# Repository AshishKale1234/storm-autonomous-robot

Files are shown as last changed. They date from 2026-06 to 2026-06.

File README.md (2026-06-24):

# Autonomous Ball-Launching Robot — STORM Competition

**ME 588 Mechatronics | Purdue University | Spring 2026**

An autonomous ground robot that follows IR-guided tape paths, classifies opponent-controlled targets via IR beacon frequency detection, and launches foam balls using a BLDC flywheel — all within a 2:30 match window from a single button press.

---

## Overview

The STORM (Send Teams Orbs to Remain Monarchs) competition places two robots on a 4 ft x 8 ft field. Each robot starts at HOME BASE, follows taped paths to four HILLs (raised buckets 12 inches above the surface), reads IR beacons to determine opponent allegiance (750 Hz = Blue, 1500 Hz = Red), and launches foam balls to flip control. Most HILLs at time expiry wins.

Team 12 (**TREBUCHET**) achieved full autonomous operation across multiple complete 2:30 runs: correct navigation to all four junctions, accurate IR classification, and consistent ball delivery into opponent buckets.

| Side | Top | Front |
|:---:|:---:|:---:|
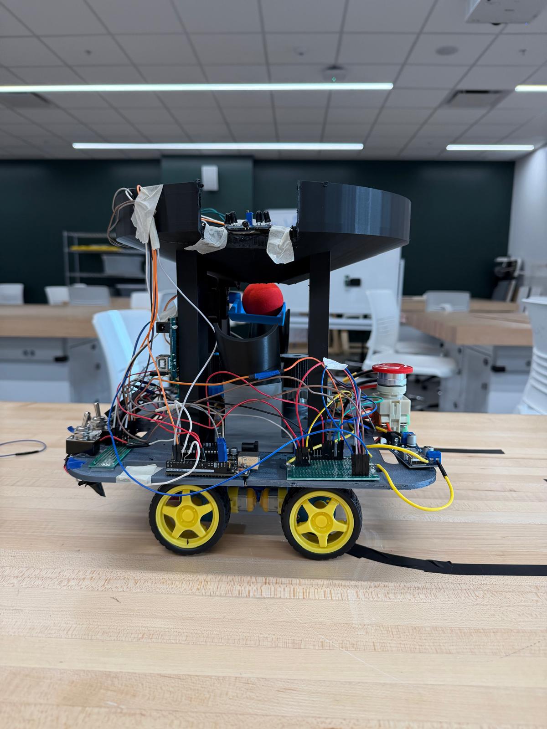
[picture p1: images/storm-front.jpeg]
Side view
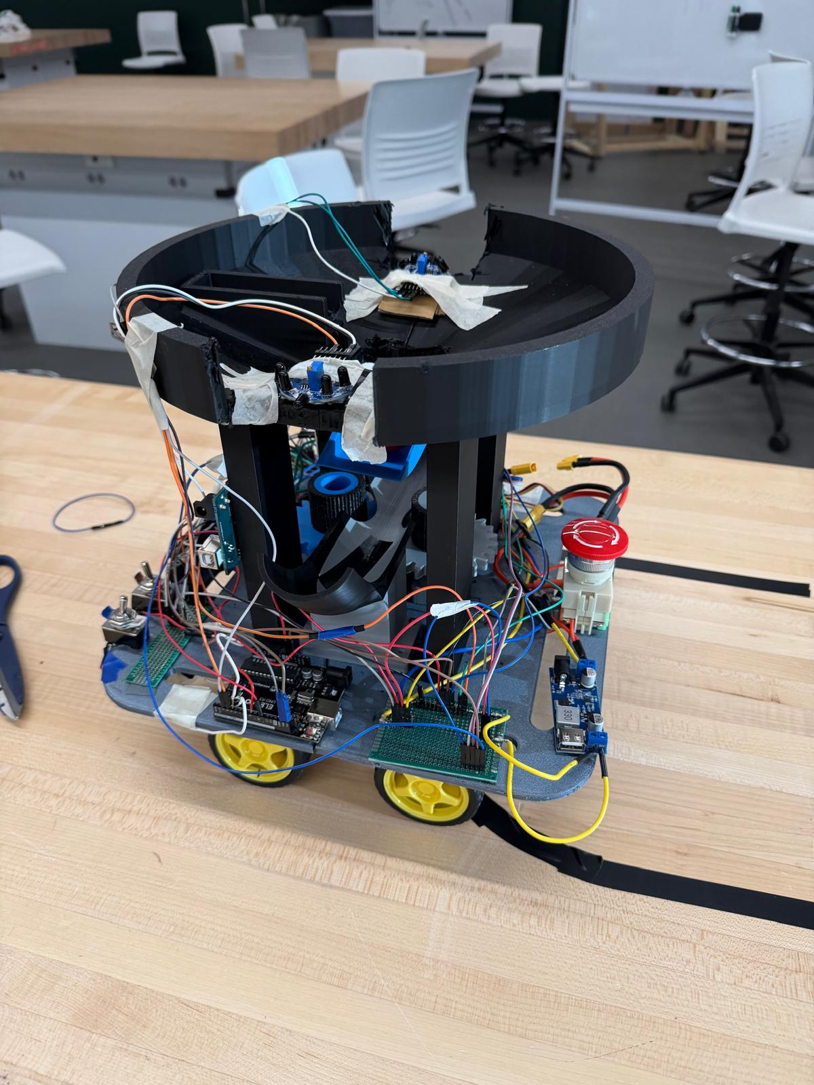
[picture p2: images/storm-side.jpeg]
Top view
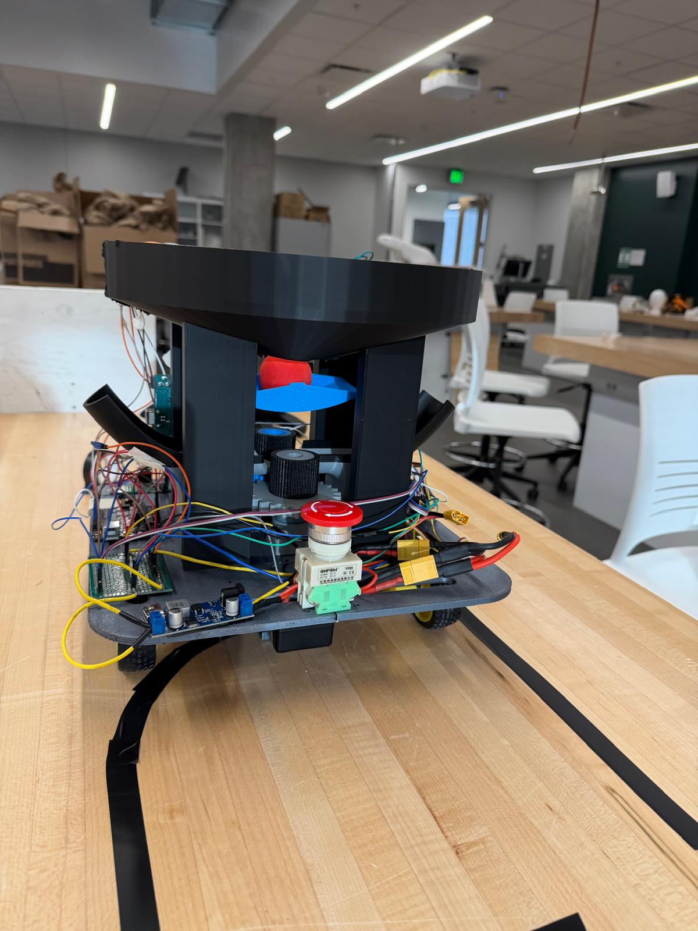
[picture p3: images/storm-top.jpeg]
Front view
|  |  |  |

---

## System Architecture

```
                 +-----------------+
                 |   Arduino 1     |  IR sensing, game timer, LCD, serial TX
  IR Sensor 1 --| D2 (interrupt)  |
  IR Sensor 2 --| D3 (interrupt)  |
  Start Toggle--| D4              |
  Team Toggle --| D5              |
      LCD I2C --| A4/A5           |
                 |   D11 (TX) ----+------> D10 (RX)  |
                 +-----------------+                   |
                                                       v
                 +-----------------+
                 |   Arduino 2     |  Motion, FSM, launcher
  SparkFun Arr--| A4/A5 (I2C)    |
  PCA9685 0x40--| A4/A5 (I2C)    |--> L298N --> 4x DC Motors
  PCA9685 0x41--| A4/A5 (I2C)    |--> ESC  --> BLDC + Flap Servo
                 +-----------------+
```

I2C addresses: `0x3E` line array, `0x40` drive PCA9685 (1000 Hz), `0x41` shooter PCA9685 (50 Hz), `0x27` LCD (Arduino 1).

---

## Hardware

| Component | Part |
|---|---|
| Microcontrollers | 2x Arduino Uno |
| Drive motors | 4x DC geared motors, L298N H-bridge |
| PWM expander (drive) | PCA9685 @ 0x40, 1000 Hz |
| PWM expander (launcher) | PCA9685 @ 0x41, 50 Hz |
| Line sensor | SparkFun 8-sensor IR reflectance array @ 0x3E |
| IR beacon sensors | 2x flame sensor modules (left + right) |
| Launcher motor | QWinOut A2212 1000KV brushless motor |
| ESC | 30A SimonK ESC (bidirectional) |
| Power | 12V battery, LM2596 buck converter (5V logic rail) |
| Display | 16x2 multicolor LCD @ 0x27 |
| Chassis | Dual-layer prefabricated steel plates |

**CAD and 3D-printed files** (in `hardware/`):

| File | Description |
|---|---|
| `Spur Gear 24 teeth drive.step` | Driver gear on BLDC shaft |
| `Spur Gear 24 teeth driven.step` | Driven gear coupled to flywheel base |
| `Driven_base.step` | Flywheel base hub |
| `TPU_sleeve.step` | TPU friction sleeve on flywheel |
| `launcher_ramp.step` | Curved ball exit ramp (direction per team) |
| `Hopper_part 1.STL` / `Hopper_part 2.STL` | Conical ball hopper (black PLA) |
| `ball_holder_flap.STL` | Servo-actuated gate flap (blue material) |
| `Body1_wdisplay.stl` / `Body2_wdisplay.stl` | LCD mounting bracket |
| `Body3_forcam.stl` / `Body4_forcam.stl` | Chassis body panels |
| `battery_chassis_attachment.STL` | Battery bracket |
| `Final_Project_KiCAD.pdf` | Full circuit schematic |
| `Final_E-Connections.docx` | Electrical connections reference |

> Replication requires the full mechanical assembly. Firmware alone is not sufficient without the matching physical hardware.

---

## Firmware

### Arduino 1 — Sensing and Game Logic
`firmware/Arduino_1/Arduino_1.ino`

- Interrupt-driven pulse counting on D2/D3; samples every 250 ms and classifies frequency as Self, Opponent, or No Signal
- Frequency windows: 600-900 Hz (750 Hz Blue beacon), 1300-1700 Hz (1500 Hz Red beacon)
- Runs 2:30 countdown timer, updates LCD every 200 ms
- Sends `TEAM:*` and `TARGET:*` messages to Arduino 2 every 500 ms and immediately on any change

### Arduino 2 — Motion and Launcher Control
`firmware/Arduino_2/Arduino_2.ino`

- 9-state FSM: IDLE, ESC_ARMING, GRACE, HOME_BYPASS, LINE_FOLLOW, JCT_DRIVE, IR_VOTE, LAUNCH, STOPPED
- PD line following with weighted-average position from 8-sensor array
- 5-second vote window at each junction; fires only if `votesOpponent > votesSelf AND votesOpponent >= 3`
- 8-phase non-blocking launch sequence: direction settle, spinup, flap open, flap return, ESC off, resume boost
- Global STOP override honored within one loop iteration from any state

### Serial Protocol (Arduino 1 -> Arduino 2, 9600 baud)

| Message | Meaning |
|---|---|
| `START` / `STOP` | Begin run / kill all |
| `TEAM:RED` / `TEAM:BLUE` | Set team color |
| `TARGET:OPPONENT` | Opponent HILL detected — vote to fire |
| `TARGET:SELF` | Own HILL detected — vote to skip |
| `TARGET:NONE` | No signal — abstain |

---

## Key Design Decisions

**Dual PCA9685** — Drive motors need 1000 Hz PWM; the ESC and flap servo need 50 Hz. A single board switching frequencies caused ESC direction glitches. Dedicated boards per domain fixed this completely.

**ESC neutral arming** — The bidirectional ESC latches direction from the signal wire during its 3-second arming window. Arming at the team angle (0 or 180 degrees) locked out the opposite direction. Arming always at 90 degrees neutral, then switching post-arm, made team color changes reliable.

**Vote-based launch gating** — A single IR classification is unreliable at range. Accumulating votes over 5 seconds and requiring both a majority and minimum count of 3 opponent votes filters transient noise without meaningfully delaying the decision.

**Dual-Arduino split** — IR frequency measurement uses hardware interrupts with tight 250 ms windows. Sharing a board with I2C traffic to two PCA9685s degraded classification accuracy. Splitting onto separate Arduinos with SoftwareSerial isolated the two timing domains.

---

## Calibration Parameters

| Parameter | Value |
|---|---|
| KP / KD / KI | 0.35 / 0.40 / 0.00 |
| BASE / CURVE / PIVOT speed | 1100 / 1500 / 3000 PWM |
| Junction sensor threshold | 5 sensors active |
| Junction cooldown | 800 ms |
| Vote window | 5000 ms |
| Min opponent votes to fire | 3 |
| ESC launch throttle | 0.27 (27%) |
| Flywheel spinup | 1500 ms |
| Flap hold / return | 600 ms / 600 ms |
| Flap angle Blue / Red / Center | 15 / 165 / 90 degrees |
| ESC direction Blue / Red | 0 / 180 degrees |
| ESC arming reference angle | 90 degrees |
| IR window 750 Hz | 600-900 Hz |
| IR window 1500 Hz | 1300-1700 Hz |

---

## Dependencies

**Arduino 1:** `Wire.h`, `SoftwareSerial.h` (built-in), `LiquidCrystal_I2C`

**Arduino 2:** `Wire.h`, `SoftwareSerial.h` (built-in), `Adafruit_PWMServoDriver`, `sensorbar.h`

- Adafruit PWM Servo Driver: https://github.com/adafruit/Adafruit-PWM-Servo-Driver-Library
- SparkFun Line Follower Array: https://github.com/sparkfun/SparkFun_Line_Follower_Array_Arduino_Library

---

## Repository Structure

```
storm-autonomous-robot/
├── README.md
├── firmware/
│   ├── Arduino_1/Arduino_1.ino
│   └── Arduino_2/Arduino_2.ino
├── hardware/
│   ├── Spur Gear 24 teeth drive.step
│   ├── Spur Gear 24 teeth driven.step
│   ├── Driven_base.step
│   ├── TPU_sleeve.step
│   ├── launcher_ramp.step
│   ├── Hopper_part 1.STL
│   ├── Hopper_part 2.STL
│   ├── ball_holder_flap.STL
│   ├── Body1_wdisplay.stl
│   ├── Body2_wdisplay.stl
│   ├── Body3_forcam.stl
│   ├── Body4_forcam.stl
│   ├── battery_chassis_attachment.STL
│   ├── Final_Project_KiCAD.pdf
│   └── Final_E-Connections.docx
├── docs/
│   └── ME588_Team12_FinalReport.pdf
└── images/
    ├── storm-front.jpeg
    ├── storm-side.jpeg
    └── storm-top.jpeg
```

---

## Team

| Ashish Kale |
| Sukesh Ranganathan | 
| Manu Vazhunnavar | 
| Pritam Ghoshal | 
| Jaemin Cho | 

**Course:** ME 588 Mechatronics, Prof. Laura Blumenschein | Purdue University | Spring 2026

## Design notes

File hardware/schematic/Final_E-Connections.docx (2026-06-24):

Electrical Setup

These are the components used.

Arduino 1 = Inputs + LCD + IR beacon detection

Arduino 2 = Line following + DC motors + shooter ESC + servo flap

LM2596 = 12V battery to regulated 5V supply

PCA9685_1=DC motors

PCA9685_2 = ESC + servo only

The high-level connections are given below.

12V Battery Positive

|---- Emergency stop switch ---- L298N +12V motor input

|------- ESC main power positive

|---- Buck Converter IN+

12V Battery Negative

|---- L298N GND

|---- ESC main power negative

|---- Buck Converter IN-

|---- Arduino 1 GND

|---- Arduino 2 GND

|---- PCA9685_1 GND

|---- PCA9685_2 GND

|---- LCD GND

|---- Sensors GND

Buck Converter:

Pin | Connect To
IN+ | Emergency Switch Terminal
IN- | 12V battery negative
OUT+ | 5V rail
OUT- | GND rail

Arduino 1:

Arduino 1 Pin | | Connect To | | Purpose
D2 | | IR beacon sensor 1 OUT | | Frequency detection
D3 | | IR beacon sensor 2 OUT | | Frequency detection
D4 | | Start toggle switch | | Start/game mode input
D5 | | Team color toggle switch | | Red/blue team selection
D8 | | LCD blue backlight control pin | | Changes LCD color
D10 | | Arduino 2 D10 | | Serial TX to Arduino 2
A4 | | LCD SDA | | I2C data
A5 | | LCD SCL | | I2C clock
5V | | Buck converter 5V OUT+ | | Power
GND | | Common GND | | Ground
Start/Stop Toggle Switch: Pin | Connect To
One side | Arduino 1 D4
Other side | GND

Team Color Toggle Switch:

Pin | Connect To
One side | Arduino 1 D5
Other side | GND

IR Sensor 1: Pin | Connect To
VCC | 5V
GND | GND
OUT / D3 | Arduino 1 D2

IR Sensor 2: Pin | Connect To
VCC | 5V
GND | GND
OUT / D3 | Arduino 1 D3

LCD:

Pin | Connect To
VCC | 5V
GND | GND
SDA | Arduino 1 SDA
SCL | Arduino 1 SCL
Pin 18 | Arduino 1 D8

Arduino 1 | Arduino 2 | Purpose
D10 | D10 | Arduino 1 TX → Arduino 2 RX
GND | GND | Common ground

Arduino 2 Pin | Connect To | Purpose
D10 | Arduino 1 D10 | Serial RX from Arduino 1
SDA | PCA9685 SDA + line follower SDA | I2C data
SCL | PCA9685 SCL + line follower SCL | I2C clock
5V | Buck Converter 5V Out+ | Power
GND | Common GND | Ground

SparkFun Line Sensor: Pin | Connect To
VCC | 5V
GND | GND
SDA | Arduino 2 SDA
SCL | Arduino 2 SCL

L298N Pin | Connect To
ENA | PCA9685_1 Ch 5
IN1 | PCA9685_1 Ch 0
IN2 | PCA9685_1 Ch 1
IN3 | PCA9685_1 Ch 2
IN4 | PCA9685_1 Ch 3
ENB | PCA9685_1 Ch 4
GND | Common GND
+12V | +12V

OUT1 Left motor pair terminal 1
OUT2 Left motor pair terminal 2
OUT3 Right motor pair terminal 1
OUT4 Right motor pair terminal 2

PCA9685_1: Pin | Connect To
VCC | 5V from Buck Converter
GND | Common GND
SDA | Arduino 2 SDA
SCL | Arduino 2 SCL
V+ | 5V from Buck Converter

PCA9685_2: Pin | Connect To
VCC | 5V from Buck Converter
GND | Common GND
SDA | Arduino 2 SDA
SCL | Arduino 2 SCL
V+ | 5V from Buck Converter
Servo: Wire | Connect To
Signal | PCA9685_2 CH1 signal
Red | PCA9685_2 V+

Black GND

ESC : Wire | Connect To
Signal | PCA9685_2 CH0 signal
Ground | PCA9685_2 GND

ESC power positive 12V battery positive

ESC power negative | Battery negative

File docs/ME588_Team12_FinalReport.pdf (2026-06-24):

# ME 588 MECHATRONICS | SPRING 2026

# Storm that Castle:

# Fight to be King of the HILL

# Final Report

# TEAM 12

# TREBUCHET | STORM

# TEAM MEMBERS

# Jagannathan Ranganathan, Sukesh

# Vazhunnavar, Manu Govind

# Cho, Jaemin

# Ghoshal, Pritam

# Kale, Ashish

# INSTRUCTOR

# Prof. Laura Blumenschein

# SUBMISSION DATE

# May 4, 2026

# INSTITUTION

# Purdue University

# School of Mechanical Engineering

# ABOUT THE TREBUCHET

# An autonomous robot designed for the STORM (Send Teams Orbs to Remain Monarchs)

competition. The bot navigates a 4 ft x 8 ft field using IR line-following, detects HILL allegiance via IR beacon frequency, and deploys 1.65-inch foam UNITs using a brushless-motor launcher with a servo-controlled hopper gate. Motion is governed by a Finite State Machine running on 2 Arduino Uno MCUs, each with a PCA9685 servo driver.

ME 588 | Team 12 | Purdue University | Spring 2026

# PURDUE UNIVERSITY | SPRING 2026

# ABSTRACT

# The report presents the design and development of an autonomous robot for the ME 588 STORM competition, in which two robots compete to control HILLs by launching foam balls into opponent-controlled buckets. Our robot uses a dual-Arduino architecture: one Arduino

handles the user interface, game timer, team selection, and IR beacon sensing, while the second controls line following, junction detection, and ball launching. The robot navigates a taped path using a SparkFun 8-sensor IR array with PID control. At the start of each run, a 3-second grace

period allows the ESC to arm, followed by a brief forward drive to bypass the home base junction. The robot then follows the line and stops at each of the four junctions where perpendicular lines point toward HILLs. At each stop, it waits 5 seconds while Arduino 1 continuously broadcasts IR beacon classifications (750 Hz for blue, 1500 Hz for red). If

opponent votes outnumber self votes and at least three opponent signals were detected, a BLDC flywheel launcher spins up, and a servo-driven flap releases a ball. Otherwise, the junction is skipped. After visiting all four junctions, the robot stops and waits for the next game to start. Two daisy-chained PCA9685 servo drivers run at different frequencies to independently control the drive motors and the launcher.

ME 588 TEAM 12 | 2

# INTRODUCTION

# Overview of Project Objective

# The STORM (Send Teams Orbs to Remain Monarchs) competition requires each team to build a

fully autonomous robot that navigates a 4 ft by 8 ft playing field, identifies opponent-controlled HILLs, and delivers foam balls into them to flip their allegiance. HILLs are square buckets positioned along the side rail of the field, 12 inches above the playing surface, and each one broadcasts its current allegiance using an IR LED beacon at a set frequency: 750 Hz for blue and 1500 Hz for red. A match lasts 2 minutes and 30 seconds, and the team controlling the most HILLs when time expires wins. The robot must start within a 12-inch cube at the HOME BASE, begin operation with a single button press, and stop all movement autonomously when the timer

# runs out. Black electrical tape lines on the field connect the HOME BASE to perpendicular

branches that point at each HILL location. The robot is expected to follow these lines, recognize junctions, and make launch decisions without any human input during the match.

# Brief Introduction of Solution

Our approach splits the problem into two cooperating subsystems running on separate Arduinos connected over serial. Arduino 1 serves as the operator interface and sensor hub: it reads two

# toggle switches (system on/off and team color), runs the 2:30 game timer on an LCD, and

continuously monitors IR beacon frequencies using interrupt-driven pulse counting on dedicated left and right sensors. Every 250 milliseconds, it measures the active sensor's pulse count, classifies the frequency as self, opponent, or no signal, and broadcasts the result to Arduino 2 every 500 milliseconds. Arduino 2 handles all motion and launches autonomously. After a 3-second startup grace period for ESC arming, it drives forward briefly to clear the home base junction line, then begins PID line following. When it detects a junction (five or more sensors active simultaneously), it stops and waits up to 5 seconds, collecting the continuous stream of

# target classifications from Arduino 1. It counts the number of opponent and self-votes it

received, ignoring no-signal readings. If opponent votes outnumber self-votes and at least three opponent signals were detected, it launches a ball. Otherwise, it skips the junction and continues. After visiting all four junctions, the robot stops permanently and waits for the next START

# command. This split architecture keeps timing-sensitive IR frequency measurement isolated

from the I2C and PWM control on the other Arduino.

# Brief Introduction of Robot Design, Sensors/Actuators, Control/Motion Strategy, and Calibration

The robot is built on a custom chassis that houses two DC geared motors, driven by an L298N H-bridge. Speed and direction signals are generated by a PCA9685 servo driver at 0x40 running

# at 1000 Hz, giving smooth PWM control without audible motor whine. A second PCA9685 at

0x41 runs at 50 Hz and handles the launcher subsystem: a bidirectional BLDC motor controlled through an ESC (throttle and direction channels) and a micro servo that actuates a flap to release balls toward the correct side. Line following uses a SparkFun 8-sensor IR reflectance array at I2C address 0x3E, with a weighted-average position calculation feeding a PD controller (KP = 0.35, KD = 0.4). Junction detection triggers when five or more sensors are active simultaneously,

# with an 800 ms cooldown to prevent double-counting. The ESC requires a specific arming

sequence at startup: 3 seconds of zero throttle at a fixed reference angle of 90 degrees, after which the team-specific direction angle (0 degrees for blue, 180 degrees for red) is applied. A brief forward drive immediately after arming clears the home base junction line, so it is not mistakenly counted as the first HILL. Calibration involved tuning PID gains for stable line following, setting junction sensor thresholds to reliably detect perpendicular tape crossings, adjusting launcher throttle and flap timing for consistent ball release, and determining the correct voting thresholds to avoid false launches from transient IR noise.

# BODY

# Detailed Robot Design

The robot is built around a dual-layer chassis structure made of pre-fabricated steel plates. The lower level consists of two parallel steel chassis plates mounted vertically with a 3D-printed battery holder bracket positioned between them. This vertical orientation creates a central cavity for the 12V battery pack while maintaining structural rigidity through the steel frame. Four DC geared motors with yellow rubber wheels are mounted at the corners of the chassis, providing

# four-wheel drive. The motors are connected to an L298N H-bridge driver that receives PWM speed signals from the PCA9685 board #1, running at 1000 Hz. A SparkFun 8-sensor IR line

follower array is mounted at the front edge of the chassis, positioned low enough to detect the black electrical tape on the white playing surface.

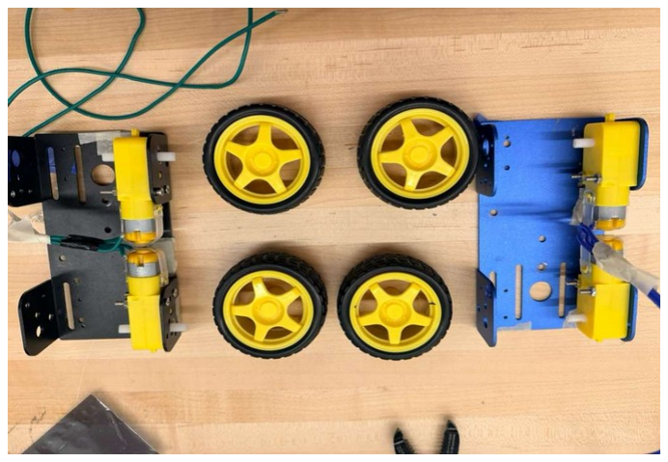
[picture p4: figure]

# Figure 1: Dual metal chassis system with motors

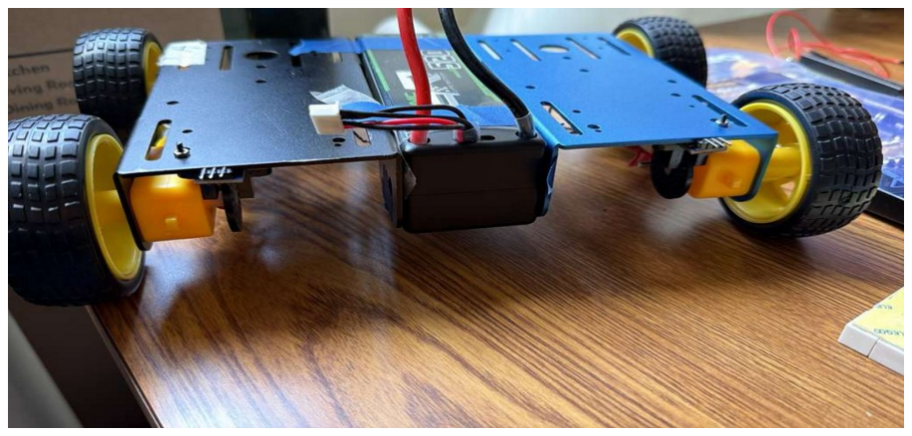
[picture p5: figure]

# Figure 2: Assembled chassis with battery

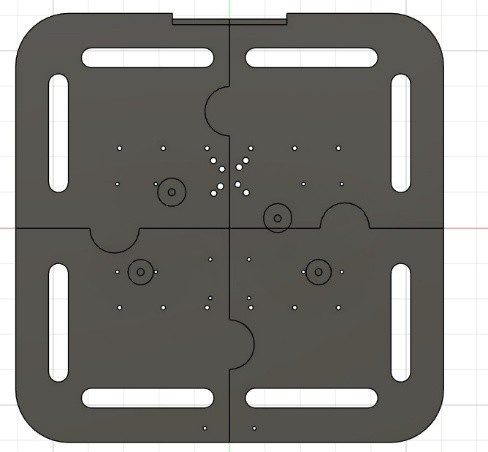
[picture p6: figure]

# Figure 3: 3D printed chassis base

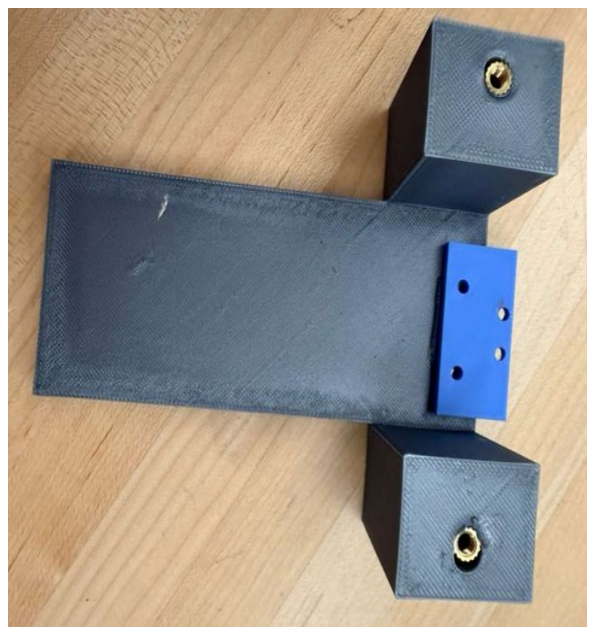
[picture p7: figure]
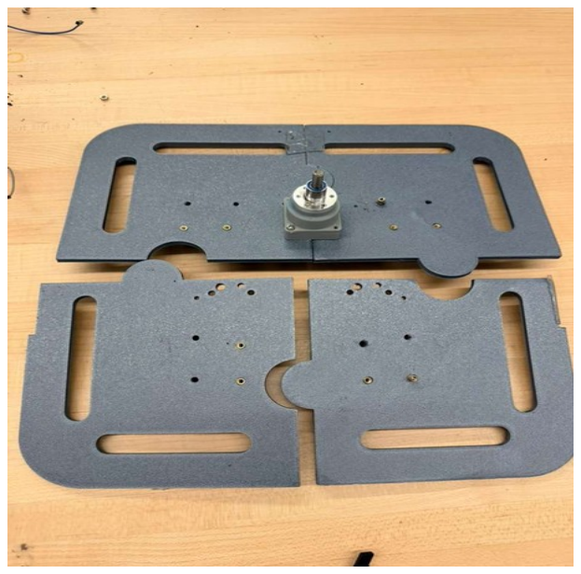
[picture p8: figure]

Above the battery cavity, a 3D-printed horizontal base plate provides the mounting surface for

# the launcher assembly. A BLDC drone motor is rigidly attached to this base with its shaft

oriented vertically. A 24-tooth spur gear (3D-printed from the drive-gear STEP file) is mounted on the motor shaft, serving as the driver gear in the launcher mechanism. A second 24-tooth spur gear (the driven gear STEP file), coupled to a flywheel base and wrapped with a TPU sleeve for improved ball grip, acts as the driven gear and is positioned adjacent to the motor gear. The TPU sleeve increases friction between the flywheel surface and the foam ball during launch. The gear mesh drives the flywheel up to launch speed when the ESC commands the motor to spin. Between the two gears, a 3D-printed curved ramp is angled so that balls rolling down from the hopper pass through the gear mesh and are accelerated by contact with the rotating TPU-wrapped flywheel surface. The ramp's curvature directs the ball's trajectory left or right, depending on the motor's rotation direction, which is controlled by the ESC's direction servo channel.

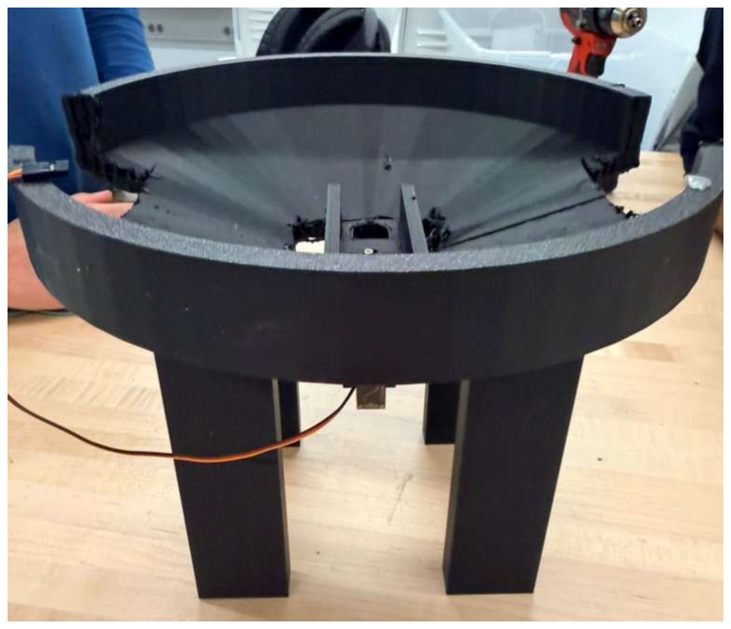
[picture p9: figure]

# Figure 6: 3D printed hopper

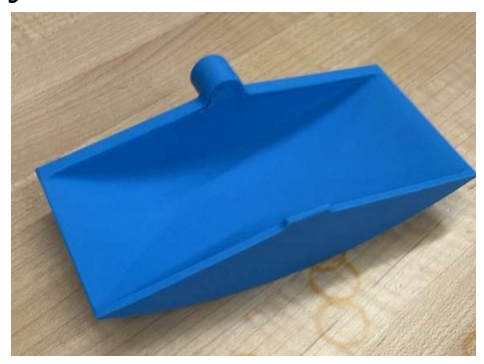
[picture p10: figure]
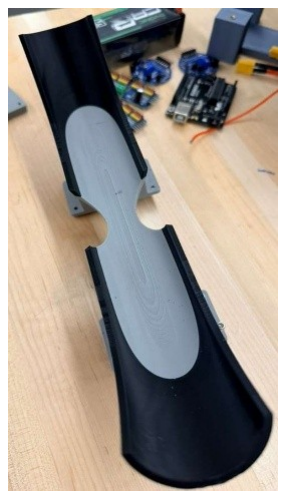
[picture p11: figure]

# At the top of the assembly, a large conical hopper made from two 3D-printed parts

(Hopper_part_1 and Hopper_part_2, printed in black PLA and joined together) houses the foam balls before launch. The hopper walls are angled inward to funnel balls toward a central opening

# directly above the flywheel and ramp. At the base of the hopper, a servo-actuated flap

Figure 4: Battery holder | Figure 5: BLDC mounted on base

# Figure 7: Ball flap

# Figure 8: Driven and drive gear

# Figure 9: Launch ramp

(ball_holder_flap.STL, printed in blue material) controls ball release. The flap is shaped like a wedge or gate. When the servo rotates to one extreme angle (15 degrees for the blue team, 165 degrees for the red team), the flap pivots aside, allowing a ball to drop through the opening onto the ramp. When the servo returns to the center position (90 degrees), the flap blocks the opening, preventing additional balls from dropping. This gated release ensures that only one ball is launched per firing sequence, and the flap angle determines which side of the ramp the ball lands on, so it exits toward the correct HILL bucket.

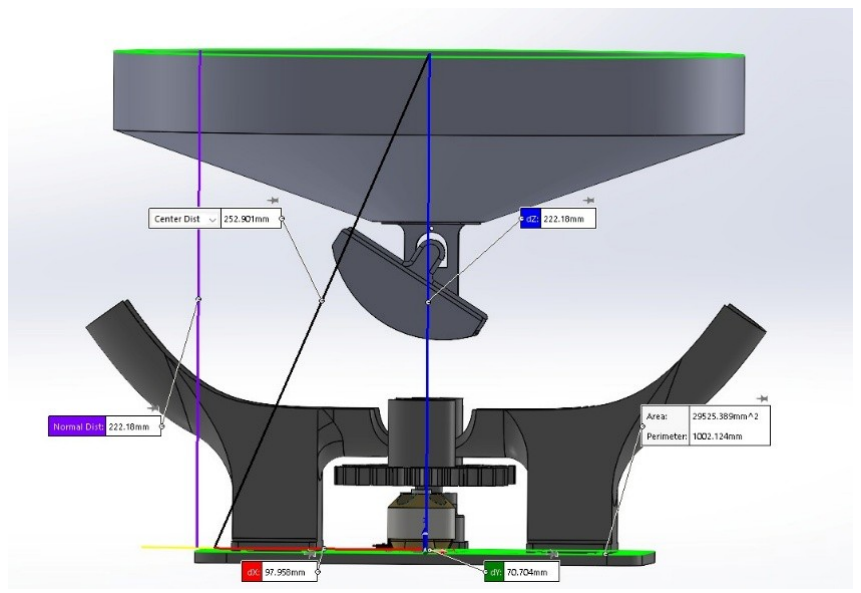
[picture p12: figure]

# Figure 10: Entire assembly

The electronics are distributed across two levels. Arduino 1, the LCD module with its 3D-printed

# mounting bracket (Body1_wdisplay and Body2_wdisplay), toggle switches, and the two IR

flame sensor modules are mounted on or near the top deck for easy operator access. Arduino 2, both PCA9685 boards, and the L298N driver are mounted lower on the steel chassis to minimize the distance to the drive motors. An LM2596 buck converter steps the 12V battery voltage down to 5V for the logic and sensor power rails. All I2C devices share a common bus: the line sensor

# array at 0x3E, PCA #1 at 0x40, PCA #2 at 0x41, and the LCD's I2C backpack at 0x27. Power

distribution uses a star topology with heavy-gauge wires running from the battery to the buck

# converter, the L298N motor supply input, and the ESC power input, with thinner wires

branching to the 5V logic devices. The entire assembly fits within a 12-inch cube envelope when measured from the bottom of the wheels to the top of the hopper.

# Detailed Motion Planning

The robot navigates the playing field using a weighted-average line-following algorithm with the SparkFun 8-sensor IR reflectance array. Each sensor is assigned a position coordinate from -3.5 to +3.5 relative to the array center. The software sums the positions of all active sensors and divides by the count to produce a signed error value. This error feeds a PD controller (KP = 0.35, KD = 0.4) that generates a correction term added to the left motor and subtracted from the right motor, steering the robot back toward the line. When centered, both motors run at the base speed

# of 1100 PWM counts. Junction detection triggers when five or more sensors activate

simultaneously. The robot then drives forward for 200 milliseconds to position the launcher over the junction, stops, and begins the target-voting phase. After launching or skipping, it resumes with a brief speed boost. At startup, a 750-millisecond forward drive bypasses the home base junction line, with detection disabled for the first 800 milliseconds to prevent miscounting.

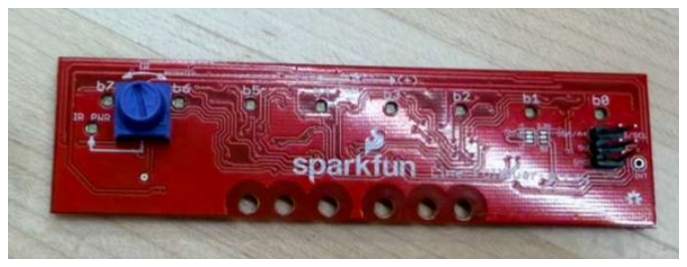
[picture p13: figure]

# Figure 11: SparkFun IR Sensor Array

# Detailed Sensor and Actuator Calibration

The IR beacon detection system required careful frequency discrimination to distinguish between

# the 750 Hz blue hill beacons and 1500 Hz red hill beacons. Two flame sensor modules were

mounted on opposite sides of the robot, with the right sensor monitoring red hills and the left sensor monitoring blue hills. Each sensor's output triggers an interrupt on Arduino 1 that increments a pulse counter. Every 250 milliseconds, the software calculates the frequency and classifies it using empirically tuned windows of 600-900 Hz for the 750 Hz beacon and 1300-1700 Hz for the 1500 Hz beacon. The operator interface consists of three switches and a 16x2 multicolor LCD. A main toggle switch on pin D4 controls start and stop, a second toggle on pin

# D5 selects team color (latched at startup to prevent mid-game changes), and a hardware

emergency stop switch sits in series with the power supply.

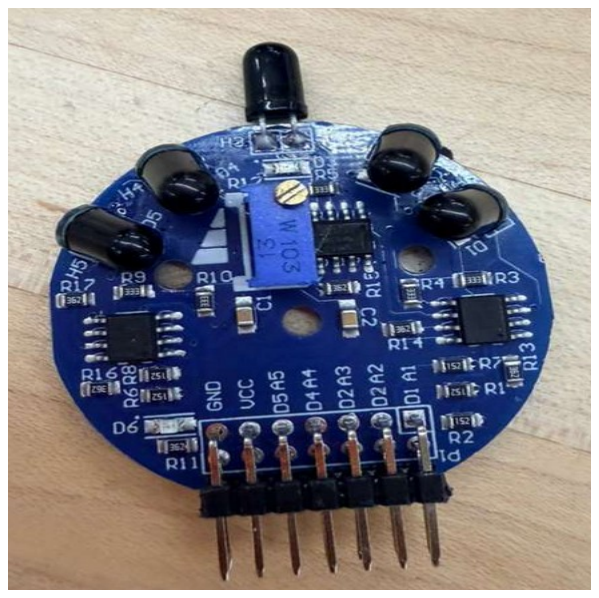
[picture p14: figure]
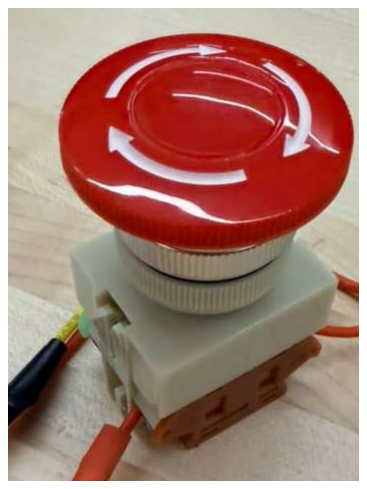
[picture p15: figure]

# Figure 12: Flame Sensor Figure 13: Emergency Switch

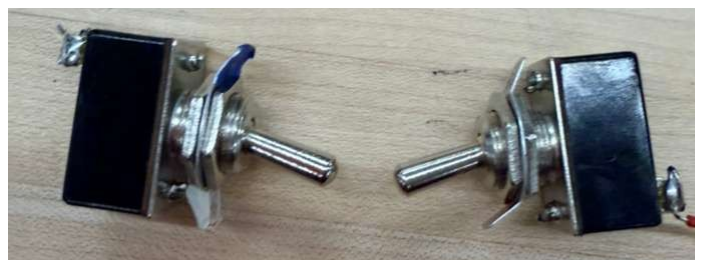
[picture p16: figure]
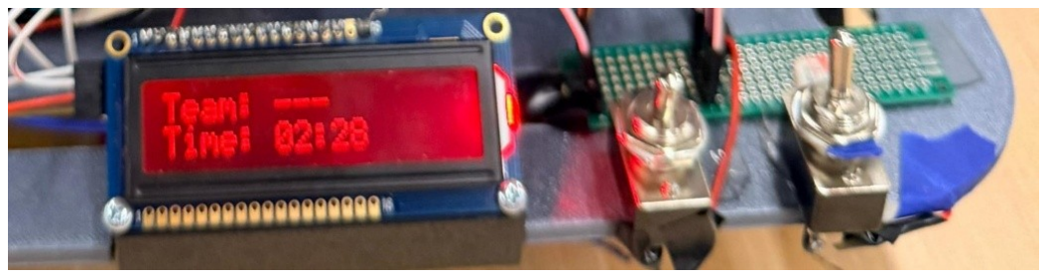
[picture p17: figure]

# Figure 15: Display

The LCD connects via I2C at address 0x27 and displays IR detection state and countdown timer,

# with backlight color matching the selected team. Pin D8 controls LCD color using

# Figure 14: 2 Toggle switches

# INPUT_PULLUP for red and OUTPUT LOW for blue, providing stable switching. The

SparkFun 8-sensor line follower array was calibrated by testing different thresholds, settling on five active sensors for reliable junction detection with an 800-millisecond cooldown to prevent double-counting. Each sensor was assigned a position coordinate from -3.5 to +3.5 for weighted-average error calculation.
PID controller gains were tuned iteratively on the field, with KP increased to 0.35 for responsive steering and KD set to 0.4 to dampen oscillations during curve-to-straight transitions. Integral gain remained at zero since sustained drift was never observed. Base speed was set to 1100 PWM counts, curve speed to 1500 when line position exceeded 1.0 units from center, and pivot speed to 3000 for sharp turns above 1.8 units. A 0.05-unit center deadband prevents unnecessary

# corrections. The ESC arming sequence required precise timing: during the 3-second arming

window, the direction signal is held at 90 degrees neutral while throttle remains at zero, and only after arming completes does the software apply the team-specific direction angle (0 degrees for blue, 180 degrees for red). Attempting to arm the team angle directly caused incorrect ESC latching. Launch throttle was calibrated incrementally from 0.20 to 0.30, settling at 0.27 to ensure consistent delivery into 12-inch-high HILL buckets. Flap servo angles (15 degrees for blue, 165 degrees for red) were determined by manual rotation until the flap fully cleared the hopper opening. The 600-millisecond flap hold duration allows complete ball release, with a second 600-millisecond hold at center, ensuring the servo physically returns before the next cycle.

# Detailed Control Strategy

# The robot's control system is implemented as a finite-state machine with 9 states (S0-S8)

controlled by an 8-bit input register. Each input bit represents a specific condition: bit 0

(START_CMD) signals a start request from the operator, bit 1 (STOP_CMD) signals a stop request, bit 2 (JCT_DETECT) is high when five or more line sensors are active, bit 3 (T_ARM_DONE) is set when the 3-second ESC arming timer expires, bit 4 (T_GRACE_DONE) is set after the 10-second startup grace period, bit 5 (T_BYPASS_DONE)

is set after the 750-millisecond home base bypass drive, bit 6 (T_JCT_DONE) is set after the

# 200-millisecond junction alignment drive, and bit 7 (VOTE_FIRE) is set when the IR voting condition (OPP_VOTES > SELF_VOTES AND OPP_VOTES ≥ 3) evaluates true. A separate 4-

bit junction counter tracks the number of junctions processed. State outputs control the drive motors (O0), the ESC direction servo (O1), the ESC throttle (O2), the flap servo (O3), the PID controller activation (O4), the vote collection logic (O5), and the junction counter increment (O6).
State transitions are triggered by specific input bit patterns shown in hex. From S0 (IDLE), the

START signal alone (input = 0x01) advances to S1 (ESC_ARMING), where the ESC direction is held at 90 degrees with zero throttle. The arming timer expiration (0x08) moves to S2 (GRACE), the grace timer (0x10) advances to S3 (HOME_BYPASS), and the bypass timer (0x20) reaches S4 (LINE_FOLLOW). In S4, junction detection (0x04) transitions to S5 (JCT_DRIVE), which advances the alignment timer (0x40) to S6 (IR_VOTE). From S6, a

successful vote (0x80) launches the ball through S7, while a failed vote or timeout (0x00) skips

# back to S4. After four junctions (JCT_CNT=4), S4 transitions to the terminal state S8 (STOPPED). A global override applies to every state: STOP_CMD (0x02) immediately returns

the FSM to S0, killing all actuators regardless of current operation. This non-blocking state machine runs on Arduino 2 and evaluates all input bits each loop iteration, ensuring the STOP override is honored within milliseconds of receipt.

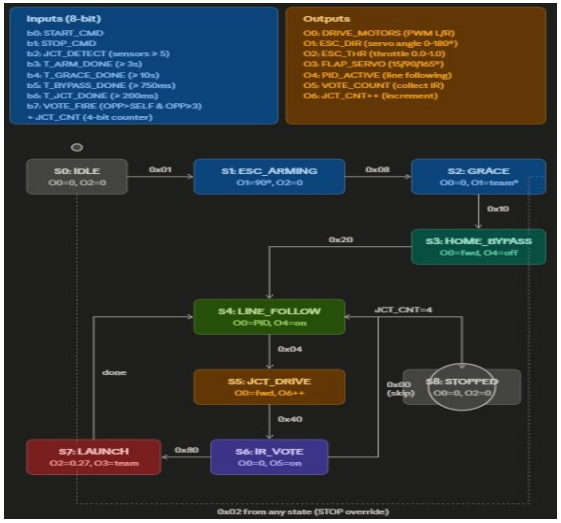
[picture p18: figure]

# Figure 16: High-level FSM

# Results

The launcher ramp required the most iterations of any single component. Its curved geometry had to send the foam ball into the HILL bucket, 12 inches above the playing surface, and early prints either launched too low (the ball striking the bucket wall) or too high (overshooting entirely). Several adjustments to the ramp curvature and exit angle, along with corresponding 3D-print iterations, eventually produced a profile that consistently delivered balls into the bucket from the junction-stopping positions. The servo-controlled flap also went through a redesign. The first version was too thick and protruded into the ball's exit path, causing balls to catch on its edge and jam during launch. A thinner, redesigned flap cleared the trajectory completely once the servo reached the team angle, after which ball release became reliable across both team configurations.

Sensor calibration required tuning the onboard potentiometers on the SparkFun line array and both IR flame sensor modules. The line array threshold was adjusted to reliably distinguish black tape from the white floor under testing-area lighting. At the same time, the flame sensors were tuned to detect the beacon LEDs at a distance in the field without picking up ambient IR noise. Both adjustments were made by observing live serial output with known inputs. Drive speed was the final calibration step: speeds below 900 PWM counts caused stalling on starts and during curves, while speeds above 1500 PWM counts caused oscillation and missed junctions. The final base speed of 1100 PWM counts gave smooth tracking with reliable junction detection. Across multiple full-match runs, the robot reliably executed the start sequence, navigated to all four HILL junctions, made correct launch decisions from IR classifications, and delivered balls into opponent-controlled buckets within the 2:30 game timer.

# Discussion

The completed robot met all major project objectives: it operated autonomously after a single button press, followed the taped path using PID control, identified opponent-controlled HILLs via IR beacon frequency classification, and accurately launched foam balls into target buckets, all within the 2:30 match window. Two significant constraints shaped the final design. The first was a signal conflict on the PCA9685 servo driver: the drive motors required high-frequency

# PWM (1000 Hz) to avoid audible whine and provide smooth control, while the BLDC ESC and

flap servo required standard 50 Hz servo pulses. Initial attempts to switch a single PCA9685

between frequencies on demand caused glitches in the ESC direction signal, preventing bidirectional mode from engaging reliably. We resolved this by adopting a dual PCA9685 architecture, with one board permanently set to 1000 Hz for the L298N drive motors and a second board fixed at 50 Hz for the launcher and flap. The second constraint involved the

bidirectional ESC's arming behavior: the ESC latched its direction reference from the yellow signal wire during the arming window, so arming with the team-specific direction angle (0° or 180°) caused the ESC to lock out the opposite direction, making it impossible to switch teams without rebooting. The fix was to always arm at a fixed neutral reference angle of 90°, regardless of team, then switch to the team-specific direction only after the 3-second arming sequence

# completed. This made team color switching symmetric and reliable, and removed a class of

unpredictable launch failures that had plagued earlier integration tests.

# Conclusion

The team successfully designed, built, and tested an autonomous robot that meets all functional

# requirements of the STORM competition: line following, junction detection, IR beacon

classification, ball launching, and start/stop control within the 2:30 match window. The dual-Arduino architecture proved effective for separating timing-sensitive sensing from actuator control, and the dual-PCA9685 setup resolved the frequency conflict between drive motors and the launcher subsystem. Future work would focus on adding a reverse-patrol mode to revisit

# junctions during the match, improving launch consistency with a closed-loop ESC throttle

controller, and reducing the 5-second IR voting window by enabling faster sensor sampling for more responsive launch decisions.

# Appendix

Our team successfully cleared all requirements for the project checkoff on 29th April 2026.

# Arduino_1.ino

#include <Wire.h>

#include <LiquidCrystal_I2C.h>

#include <SoftwareSerial.h>

// ===================================================== // SERIAL TO ARDUINO 2
// ===================================================== //
// Arduino 1 D10 = RX, connect to Arduino 2 D11
// Arduino 1 D11 = TX, connect to Arduino 2 D10
//
const byte ARDUINO2_RX_PIN = 10;
const byte ARDUINO2_TX_PIN = 11;

SoftwareSerial arduino2Link(ARDUINO2_RX_PIN, ARDUINO2_TX_PIN);

// =====================================================
// LCD
// ===================================================== // Change 0x27 to 0x3F if needed.
LiquidCrystal_I2C lcd(0x27, 16, 2);

// ===================================================== // PINS ON ARDUINO 1
// =====================================================
const byte SENSOR1_PIN = 2; | | // Blue team active sensor
const byte SENSOR2_PIN = 3; | | // Red team active sensor
const byte START_SWITCH_PIN = 4; | // Start/Stop toggle
const byte TEAM_SWITCH_PIN | = 5; | // Team color toggle
const byte LCD_BLUE_CTRL_PIN = 8; | // LCD pin 18 blue control

// =====================================================
// SETTINGS
// =====================================================
const unsigned long GAME_TIME_MS | = 150000UL; // 2 min 30 sec
const unsigned long MEASURE_WINDOW_MS = 250UL;
const unsigned long LCD_UPDATE_MS | = 200UL;
const unsigned long COMMAND_REPEAT_MS = 50UL;
const unsigned long STATUS_SEND_MS | = 500UL;
const float FREQ_750_MIN | = 600.0;
const float FREQ_750_MAX | = 900.0;
const float FREQ_1500_MIN = 1300.0;
const float FREQ_1500_MAX = 1700.0;

// ===================================================== // STATE
// =====================================================

volatile unsigned long pulseCount1 = 0;
volatile unsigned long pulseCount2 = 0;

unsigned long gameStartTime = 0; unsigned long lastMeasureTime = 0;
unsigned long lastLcdUpdate | = 0;
unsigned long lastStatusSend | = 0;

bool systemIsOn = false;
bool gameOver = false;
bool lastStartSwitchState = false;

enum TeamColor {
BLUE_TEAM = 0,
RED_TEAM = 1
};

enum DetectionState {
NO_SIGNAL = 0,
DETECT_SELF,
DETECT_OPPONENT
};

TeamColor currentTeam = BLUE_TEAM; TeamColor lastSentTeam = BLUE_TEAM;

DetectionState currentDetection = NO_SIGNAL; DetectionState lastSentDetection = NO_SIGNAL;

// Non-blocking repeated command sender
bool repeatCommandActive = false;
const char* repeatCommandText = ""; unsigned int repeatCommandRemaining = 0;
unsigned long lastRepeatCommandTime = 0;

// ===================================================== // INTERRUPTS
// =====================================================

void countPulse1() {
pulseCount1++;
}

void countPulse2() {
pulseCount2++;
}

// ===================================================== // SWITCH HELPERS
// ===================================================== //
// INPUT_PULLUP logic:
// Switch connected to GND = ON / LOW
//

bool startSwitchOn() {
return digitalRead(START_SWITCH_PIN) == LOW;
}

TeamColor getTeam() {
if (digitalRead(TEAM_SWITCH_PIN) == LOW) { return BLUE_TEAM;
} else {
return RED_TEAM;
}
}

// ===================================================== // LCD COLOR
// ===================================================== //
// LCD color behavior:
// default = RED
// grounding LCD pin 18 = BLUE
//

void setLCDColor(TeamColor team) {
if (team == BLUE_TEAM) {
pinMode(LCD_BLUE_CTRL_PIN, OUTPUT); digitalWrite(LCD_BLUE_CTRL_PIN, LOW);

} else {
pinMode(LCD_BLUE_CTRL_PIN, INPUT);
}
}

// ===================================================== // LCD HELPERS
// =====================================================

void lcdSystemOff() {
lcd.noBacklight();
lcd.clear();
}

void lcdSystemOn() {
lcd.backlight();
lcd.clear();
}

void printLine(byte row, String text) { const int LCD_WIDTH = 16;

if (text.length() < LCD_WIDTH) { while (text.length() < LCD_WIDTH) { text += " ";
}
} else if (text.length() > LCD_WIDTH) { text = text.substring(0, LCD_WIDTH);
}

lcd.setCursor(0, row);
lcd.print(text);
}

String formatTimeRemaining(unsigned long elapsedMs) { unsigned long remainingMs = 0;

if (elapsedMs < GAME_TIME_MS) {
remainingMs = GAME_TIME_MS - elapsedMs;
}

unsigned long totalSeconds = remainingMs / 1000; int minutes = totalSeconds / 60;
int seconds = totalSeconds % 60;

char buf[17];
sprintf(buf, "Time: %02d:%02d", minutes, seconds); return String(buf);
}

String detectionText(DetectionState state) { if (state == DETECT_SELF) {
return "Team: Self";
}

if (state == DETECT_OPPONENT) { return "Team:Opponent";
}

return "Team: ---";
}

// ===================================================== // SENSOR HELPERS
// =====================================================

void resetPulseCounters() {
noInterrupts();
pulseCount1 = 0;
pulseCount2 = 0;
interrupts();
}

float getActiveSensorFrequency(TeamColor team) { unsigned long count1;
unsigned long count2;

noInterrupts();
count1 = pulseCount1;
count2 = pulseCount2;
pulseCount1 = 0;
pulseCount2 = 0;
interrupts();

unsigned long activeCount = 0;

if (team == BLUE_TEAM) {
activeCount = count1;
} else {
activeCount = count2;
}

return (activeCount * 1000.0) / MEASURE_WINDOW_MS;
}

DetectionState classifyFrequency(float freq, TeamColor team) {
bool is750 | = (freq > FREQ_750_MIN | && freq < FREQ_750_MAX);
bool is1500 = (freq > FREQ_1500_MIN && freq < FREQ_1500_MAX);

if (!is750 && !is1500) {
return NO_SIGNAL;
}

if (team == RED_TEAM) {
// Bucket loyal to RED blinks at 1500 Hz. // So for RED team:
// 1500 Hz = Self
// 750 Hz = Opponent
if (is1500) return DETECT_SELF;
if (is750) return DETECT_OPPONENT;
} else {
// Bucket loyal to BLUE blinks at 750 Hz. // So for BLUE team:
// 750 Hz = Self
// 1500 Hz = Opponent
if (is750) return DETECT_SELF; if (is1500) return DETECT_OPPONENT;
}

return NO_SIGNAL;
}

// ===================================================== // SERIAL COMMAND HELPERS
// =====================================================

void sendCommand(const char* command) { arduino2Link.println(command);
}

void startRepeatingCommand(const char* command, unsigned int times) { repeatCommandText = command;
repeatCommandRemaining = times;
repeatCommandActive = true;
lastRepeatCommandTime = 0;
}

void updateRepeatingCommand() { if (!repeatCommandActive) { return;
}

if (repeatCommandRemaining == 0) { repeatCommandActive = false;

return;
}

unsigned long now = millis();

if (lastRepeatCommandTime == 0 || now - lastRepeatCommandTime >= COMMAND_REPEAT_MS) { sendCommand(repeatCommandText);
lastRepeatCommandTime = now;
repeatCommandRemaining--;
}
}

void sendTeamToArduino2(TeamColor team) { if (team == BLUE_TEAM) {
sendCommand("TEAM:BLUE");
} else {
sendCommand("TEAM:RED");
}

lastSentTeam = team;
}

void sendTargetToArduino2(DetectionState state) { if (state == DETECT_SELF) { sendCommand("TARGET:SELF");
} else if (state == DETECT_OPPONENT) { sendCommand("TARGET:OPPONENT");
} else {
sendCommand("TARGET:NONE");
}

lastSentDetection = state;
}

void sendCurrentStatusToArduino2() { sendTeamToArduino2(currentTeam); sendTargetToArduino2(currentDetection);
}

void updateStatusMessages() {
unsigned long now = millis();

bool teamChanged = currentTeam != lastSentTeam;
bool detectionChanged = currentDetection != lastSentDetection; bool periodicSend = now - lastStatusSend >= STATUS_SEND_MS;

if (teamChanged) {
sendTeamToArduino2(currentTeam);
}

if (detectionChanged) {
sendTargetToArduino2(currentDetection);
}

if (periodicSend) {
sendCurrentStatusToArduino2(); lastStatusSend = now;
}
}

// ===================================================== // READ REPLIES FROM ARDUINO 2
// =====================================================
//
// Replies are ignored. This prevents the SoftwareSerial buffer // from filling up, but does not print anything.
//

void handleArduino2Reply() {
while (arduino2Link.available()) { arduino2Link.read();
}

}

// ===================================================== // START / STOP SYSTEM
// =====================================================

void startSystem() {
if (systemIsOn) {
return;
}

systemIsOn = true;
gameOver = false;

gameStartTime = millis();
lastMeasureTime = millis(); lastLcdUpdate = 0;
lastStatusSend = 0;

currentTeam = getTeam();
currentDetection = NO_SIGNAL; lastSentTeam = currentTeam; lastSentDetection = currentDetection;

resetPulseCounters();

lcdSystemOn();
setLCDColor(currentTeam);

printLine(0, "Team: ---"); printLine(1, "Time: 02:30");

sendTeamToArduino2(currentTeam); sendTargetToArduino2(currentDetection);

startRepeatingCommand("START", 3);
}

void stopSystem() {
systemIsOn = false;
gameOver = false;

currentDetection = NO_SIGNAL; resetPulseCounters();

lcdSystemOff();

pinMode(LCD_BLUE_CTRL_PIN, INPUT);

startRepeatingCommand("STOP", 10);
}

void endGameByTimer() {
systemIsOn = false;
gameOver = true;

currentDetection = NO_SIGNAL; resetPulseCounters();

startRepeatingCommand("STOP", 10);

printLine(0, "GAME OVER"); printLine(1, "Time: 00:00");
}

// ===================================================== // DETECTION UPDATE
// =====================================================

void updateDetection(TeamColor team) {
unsigned long now = millis();

if (now - lastMeasureTime >= MEASURE_WINDOW_MS) { float freq = getActiveSensorFrequency(team); currentDetection = classifyFrequency(freq, team); lastMeasureTime = now;
}
}

// ===================================================== // LCD UPDATE
// =====================================================

void updateRunningLCD(unsigned long elapsed) { unsigned long now = millis();

if (now - lastLcdUpdate >= LCD_UPDATE_MS) { printLine(0, detectionText(currentDetection)); printLine(1, formatTimeRemaining(elapsed)); lastLcdUpdate = now;
}
}

void updateGameOverLCD() {
unsigned long now = millis();

if (now - lastLcdUpdate >= LCD_UPDATE_MS) { setLCDColor(getTeam());
printLine(0, "GAME OVER");
printLine(1, "Time: 00:00"); lastLcdUpdate = now;
}
}

// ===================================================== // SETUP
// =====================================================

void setup() {
arduino2Link.begin(9600);

pinMode(SENSOR1_PIN, INPUT); pinMode(SENSOR2_PIN, INPUT);

pinMode(START_SWITCH_PIN, INPUT_PULLUP); pinMode(TEAM_SWITCH_PIN, INPUT_PULLUP);

pinMode(LCD_BLUE_CTRL_PIN, INPUT);

lcd.init();
lcd.noBacklight();
lcd.clear();

attachInterrupt(digitalPinToInterrupt(SENSOR1_PIN), countPulse1, RISING); attachInterrupt(digitalPinToInterrupt(SENSOR2_PIN), countPulse2, RISING);

lastStartSwitchState = startSwitchOn();

currentTeam = getTeam();
lastSentTeam = currentTeam; currentDetection = NO_SIGNAL; lastSentDetection = currentDetection;

if (lastStartSwitchState) { startSystem();
} else {
lcdSystemOff();
startRepeatingCommand("STOP", 10);
}
}

// ===================================================== // LOOP
// =====================================================

void loop() {
handleArduino2Reply();
updateRepeatingCommand();

bool currentStartSwitchState = startSwitchOn();

// OFF -> ON
if (currentStartSwitchState && !lastStartSwitchState) { startSystem();
}

// ON -> OFF
if (!currentStartSwitchState && lastStartSwitchState) { stopSystem();
}

lastStartSwitchState = currentStartSwitchState;

// If game ended by timer, keep LCD showing GAME OVER. // User must turn toggle OFF, then ON again to restart. if (gameOver) {
updateGameOverLCD();

if (!currentStartSwitchState) { stopSystem();
}

return;
}

if (!systemIsOn) {
return;
}

currentTeam = getTeam();
setLCDColor(currentTeam);

updateDetection(currentTeam); updateStatusMessages();

unsigned long elapsed = millis() - gameStartTime;

if (elapsed >= GAME_TIME_MS) {
endGameByTimer();
return;
}

updateRunningLCD(elapsed);
}

# Arduino_2.ino

/*
* Arduino 2 — Line Follower + Launcher (DUAL PCA9685) * GAME LOGIC VERSION
*
* Receives commands from Arduino 1 over SoftwareSerial:
* | D10 (RX) ← Arduino 1 D11 (TX)
* | Common GND
*
* Commands from Arduino 1:
* | START | — begin run with 10s startup grace period
* | STOP | — kill everything immediately, even mid-launch
* | TEAM:RED | — team is RED | → flap 165°, ESC direction A
* | TEAM:BLUE | — team is BLUE → flap 15°, | ESC direction B
* | TARGET:SELF | — IR signal from our team's bucket → SKIP (don't score own goal)

* | TARGET:OPPONENT | — IR signal from opponent's bucket → FIRE (score!)
* | TARGET:NONE | — no IR signal detected → skip
*
* GAME FLOW:
* | 1. START → 10s grace (ESC arming, robot stays still)
* | 2. Home base bypass: 0.75s straight forward (junction detection disabled)
* | — this skips the junction line at the home base
* | 3. Forward line following begins
* | 4. Junction detected → stop → wait 5s, collecting TARGET classifications
* | - Count OPPONENT vs SELF votes (ignoring NONE)
* | - If OPPONENT votes > SELF votes AND OPPONENT votes >= 3 → fire
* | - Otherwise → skip junction, resume line following
* | 5. After 4 junctions → STOP PERMANENTLY (run ends)
* | 6. Stays stopped until next START or STOP command
*
* Hardware:
* | PCA9685 #1 @ 0x40 — running at 1000Hz for L298N drive motors
* | PCA9685 #2 @ 0x41 — running at | 50Hz for ESC + flap servo
* | SparkFun Line Follower Array @ 0x3E (front-facing only)
*
* | PCA #1 (0x40, drive @ 1000Hz):
* | ch0=IN1, ch1=IN2, ch2=IN3, ch3=IN4, ch4=ENB, ch5=ENA
* | PCA #2 (0x41, shooter @ 50Hz):
* | ch0=ESC direction (yellow)
* | ch6=ESC throttle (white)
* | ch7=Flap servo
*/

#include <Wire.h>

#include <sensorbar.h>

#include <Adafruit_PWMServoDriver.h>

#include <SoftwareSerial.h>

// ============================================= // TOP-LEVEL CONFIGURATION
// =============================================

// ── Serial link ────────────────────────────── const byte ARDUINO1_RX_PIN = 10;
const byte ARDUINO1_TX_PIN = 11;

// ── Direction flags ────────────────────────── #define FLIP_MOTORS true
#define FLIP_SENSOR true

// ── Reverse line following strategy ─────────
// true = Plan A: reverse line following with reversed PID (recommended) // false = Plan B: just drive straight backwards, no line following #define USE_PID_REVERSE true

// ── ESC direction servo angles (yellow wire) ─
const int MOTOR_DIR_RED | = 180; | // direction for RED team
const int MOTOR_DIR_BLUE = 0; | // direction for BLUE team

// Reference angle used during ESC arming.
// Empirically 90 works on this ESC.
const int ESC_ARM_REF_ANGLE = 90;

// ── Flap angles per team ─────────────────────
const int FLAP_CENTER | = 90; | // resting / closed
const int FLAP_OPEN_RED | = 165; | // red team release angle
const int FLAP_OPEN_BLUE = 15; | // blue team release angle

// ── Forward PID tuning ───────────────────────
float KP = 0.35;
float KI = 0.00;
float KD = 0.4;

// ── Reverse PID tuning (smaller gains for stability) ── float KP_REV = 0.25;
float KI_REV = 0.00;
float KD_REV = 0.20;

// ── Drive speeds (PCA9685 0–4095) ────────────
int BASE_SPEED | = 1100;
int CURVE_SPEED | = 1500;
int PIVOT_SPEED | = 3000;
int SEARCH_SPEED | = 1200;
int MAX_SPEED | = 3000;
int MIN_MOTOR_SPEED | = 800;

// Reverse-mode speeds (slower for stability)
int BASE_SPEED_REV | = 600;
int CURVE_SPEED_REV | = 800;
int PIVOT_SPEED_REV | = 1500;

int START_BOOST_SPEED = 2300; unsigned long START_BOOST_MS = 180;

float CENTER_DEADBAND = 0.05; float CURVE_THRESHOLD = 1.0;
float PIVOT_THRESHOLD = 1.8;

// ── Junction settings ────────────────────────
int JUNCTION_SENSOR_COUNT | = 5;
unsigned long JUNCTION_DRIVE_MS | = 200;
int JUNCTION_FORWARD_SPEED | = 1200;
unsigned long JUNCTION_COOLDOWN_MS = 800;
const int TOTAL_JUNCTIONS | = 4; | // stop permanently after this many junctions

// ── Target detection wait at junction ───────
const unsigned long TARGET_WAIT_MS = 5000; | // 5s window to collect votes
const int MIN_OPPONENT_VOTES = 3; | | // need at least this many OPPONENT votes
| | // AND OPPONENT > SELF to fire

// ── Junction skip (no fire) settings ────────
const unsigned long SKIP_PAUSE_MS = 200; | // brief pause before resuming
const unsigned long SKIP_BOOST_MS = 250; | // boost forward to clear junction
const int SKIP_BOOST_SPEED = 1500;

// ── Shooter timing ───────────────────────────
const float TARGET_THROTTLE = 0.27;

// 10s startup grace period after START.
const unsigned long STARTUP_GRACE_MS = 3000;
const unsigned long ESC_ARM_MS | = 3000;

// After grace ends, drive forward at HOME_BASE_BYPASS_SPEED for // HOME_BASE_BYPASS_MS to physically clear the home base line.
// Then keep junction/sensor detection DISABLED for SENSOR_IGNORE_MS // (measured from the start of bypass) — this prevents the home base
// line from being counted as a junction even after the robot resumes
// normal line following.
const unsigned long HOME_BASE_BYPASS_MS = 150; | // motion duration (boost forward)
const int HOME_BASE_BYPASS_SPEED = 1800; | // motion speed
const unsigned long SENSOR_IGNORE_MS = 800; | // junction detection stays off this long
| | // (must be >= HOME_BASE_BYPASS_MS)

// Per-launch timing
const unsigned long DIR_SETTLE_MS = 300; const unsigned long SPINUP_WAIT_MS = 1500; const unsigned long FLAP_HOLD_MS = 600; const unsigned long FLAP_RETURN_MS = 600; const unsigned long POST_FLAP_MS = 1500;
const unsigned long POST_LAUNCH_MS = 2000;

// ── PCA9685 #1 channel mapping (drive @ 1000Hz, addr 0x40) ── #define CH_IN1 0
#define CH_IN2 1

#define CH_ENA 5

#define CH_IN3 2

#define CH_IN4 3

#define CH_ENB 4

// ── PCA9685 #2 channel mapping (shooter @ 50Hz, addr 0x41) ──
const int ESC_DIR_CHANNEL | = 0;
const int ESC_THR_CHANNEL | = 6;
const int FLAP_CHANNEL | = 7;

// =============================================
// GLOBALS
// ============================================= SoftwareSerial arduino1Link(ARDUINO1_RX_PIN, ARDUINO1_TX_PIN);

SensorBar bar(0x3E);
Adafruit_PWMServoDriver pwmDrive(0x40); Adafruit_PWMServoDriver pwmShoot(0x41);

enum TeamColor { TEAM_RED, TEAM_BLUE };
TeamColor currentTeam = TEAM_RED;

enum TargetState { TARGET_NONE, TARGET_SELF, TARGET_OPPONENT }; TargetState currentTarget = TARGET_NONE;

bool running = false;
unsigned long runStartTime = 0;
bool inStartupGrace = false;

// True while we're in the home base bypass phase (driving forward with // junction detection disabled) immediately after grace ends.
bool inHomeBaseBypass = false;
unsigned long homeBaseBypassStart = 0;

// Forward (true) or reverse (false) line-following direction bool forwardDirection = true;

bool escArmed = false;

enum GracePhase {
GRACE_INIT,
GRACE_ARMING,
GRACE_IDLE
};
GracePhase gracePhase = GRACE_INIT;
unsigned long gracePhaseStart = 0;

// PID state (shared across forward and reverse — reset on direction flip) float integral = 0.0;
float lastError = 0.0;
int lastKnownDir = 0;
int lastLeftSpeed = 0;
int lastRightSpeed = 0;
bool wasInTurn = false;

// Junction state
bool junctionDetected = false;
unsigned long junctionStartTime = 0;
unsigned long lastJunctionTime = 0;
int junctionCount = 0; // resets every JUNCTIONS_PER_DIRECTION

// Vote counters for the current junction wait window.
// Cleared at the start of each junction wait. Incremented every time
// a TARGET:* message arrives. NONE is counted but ignored in the decision. int votesOpponent = 0;
int votesSelf = 0;
int votesNone = 0;

// ============================================= // STATE MACHINES
// =============================================

// What to do after stopping at a junction
enum JunctionPhase {
JUNC_IDLE,
JUNC_APPROACH, | // brief forward drive after detection (to align over junction)
JUNC_WAIT_FOR_TARGET, | // 5s window: collecting TARGET votes

JUNC_SKIP_PAUSE, | // brief pause when not firing
JUNC_SKIP_BOOST | // boost through to leave the junction
};
JunctionPhase junctionPhase = JUNC_IDLE;
unsigned long junctionPhaseStart = 0;

// Launch state machine (entered when SELF is confirmed at junction) enum LaunchPhase {
LAUNCH_IDLE,
LAUNCH_SET_DIRECTION,
LAUNCH_DIR_SETTLE,
LAUNCH_SPINUP,
LAUNCH_FLAP_OPEN,
LAUNCH_FLAP_RETURN,
LAUNCH_POST_FLAP,
LAUNCH_ESC_OFF,
LAUNCH_POST_LAUNCH,
LAUNCH_RESUME_BOOST
};
LaunchPhase launchPhase = LAUNCH_IDLE;
unsigned long launchPhaseStart = 0;

// ============================================= // PCA9685 HELPERS
// ============================================= int usToCounts50Hz(int us) {
return (int)((us * 4096L) / 20000L);
}

void setShooterPulseUs(int channel, int us) { pwmShoot.setPWM(channel, 0, usToCounts50Hz(us));
}

// ── Cached last-written values for shooter board (50Hz) ──
// PCA9685 holds whatever value was last written until you change it. // Continuously re-writing the same value every loop iteration is // wasted I2C traffic AND can cause servo jitter on cheap servos
// because each I2C transaction has small timing variation.
// We cache the last value sent for each channel and only re-write // when it actually changes. -1 means "never written yet" so the // first call always goes through.
int lastEscThrottleUs = -1;
int lastEscDirAngleDeg = -1;
int lastFlapAngleDeg = -1;

void setEsc(float throttle) {
if (throttle < 0.0) throttle = 0.0;
if (throttle > 1.0) throttle = 1.0;
int us = 1000 + (int)(throttle * 1000.0);
if (us == lastEscThrottleUs) return; // no-op if unchanged setShooterPulseUs(ESC_THR_CHANNEL, us);
lastEscThrottleUs = us;
}

void setServoAngle(int channel, int degrees) {
if (degrees < 0) degrees = 0;
if (degrees > 180) degrees = 180;
int us = 1000 + (int)((degrees / 180.0) * 1000.0); setShooterPulseUs(channel, us);
}

void setFlap(int degrees) {
if (degrees < 0) degrees = 0;
if (degrees > 180) degrees = 180;
if (degrees == lastFlapAngleDeg) return; // no-op if unchanged setServoAngle(FLAP_CHANNEL, degrees);
lastFlapAngleDeg = degrees;
}

void setMotorDirectionForTeam() {
int angle = (currentTeam == TEAM_RED) ? MOTOR_DIR_RED : MOTOR_DIR_BLUE; if (angle == lastEscDirAngleDeg) return; // no-op if unchanged setServoAngle(ESC_DIR_CHANNEL, angle); lastEscDirAngleDeg = angle;
}

void setEscDirectionToArmRef() {
if (ESC_ARM_REF_ANGLE == lastEscDirAngleDeg) return; // no-op if unchanged setServoAngle(ESC_DIR_CHANNEL, ESC_ARM_REF_ANGLE);
lastEscDirAngleDeg = ESC_ARM_REF_ANGLE;
}

int getFlapOpenAngleForTeam() {
return (currentTeam == TEAM_RED) ? FLAP_OPEN_RED : FLAP_OPEN_BLUE;
}

void forceShooterChannelsOff() {
pwmShoot.setPWM(ESC_THR_CHANNEL, 0, 4096);
pwmShoot.setPWM(FLAP_CHANNEL, | 0, 4096);
// After explicitly cutting signals, invalidate caches so the next // setEsc()/setFlap() call definitely writes through. lastEscThrottleUs = -1;
lastFlapAngleDeg = -1;
}

// =============================================
// DRIVE MOTOR FUNCTIONS (PCA #1 @ 1000Hz)
// =============================================
void pinHigh(uint8_t ch) { pwmDrive.setPWM(ch, 4096, 0); } void pinLow (uint8_t ch) { pwmDrive.setPWM(ch, 0, 4096); }

void setSpeed(uint8_t ch, int speed) {
speed = constrain(speed, 0, 4095);
pwmDrive.setPWM(ch, 0, speed);
}

void stopMotors() {
setSpeed(CH_ENA, 0);
setSpeed(CH_ENB, 0);
pinLow(CH_IN1);
pinLow(CH_IN2);
pinLow(CH_IN3);
pinLow(CH_IN4);
}

void setMotors(int leftSpeed, int rightSpeed) { if (FLIP_MOTORS) {
leftSpeed = -leftSpeed;
rightSpeed = -rightSpeed;
}
leftSpeed | = constrain(leftSpeed, | -MAX_SPEED, MAX_SPEED);
rightSpeed = constrain(rightSpeed, -MAX_SPEED, MAX_SPEED);

if (leftSpeed > 0 && leftSpeed < MIN_MOTOR_SPEED) leftSpeed = MIN_MOTOR_SPEED; if (leftSpeed < 0 && leftSpeed > -MIN_MOTOR_SPEED) leftSpeed = -MIN_MOTOR_SPEED; if (rightSpeed > 0 && rightSpeed < MIN_MOTOR_SPEED) rightSpeed = MIN_MOTOR_SPEED; if (rightSpeed < 0 && rightSpeed > -MIN_MOTOR_SPEED) rightSpeed = -MIN_MOTOR_SPEED;

if (leftSpeed >= 0) {
pinHigh(CH_IN1);
pinLow(CH_IN2);
} else {
pinLow(CH_IN1);
pinHigh(CH_IN2);
}
setSpeed(CH_ENA, abs(leftSpeed));

if (rightSpeed >= 0) {
pinLow(CH_IN3);
pinHigh(CH_IN4);
} else {
pinHigh(CH_IN3);
pinLow(CH_IN4);

}
setSpeed(CH_ENB, abs(rightSpeed));
}

// =============================================
// SENSOR FUNCTIONS
// =============================================
bool sensorOn(uint8_t raw, int n) { return raw & (1 << n); }

void printRawBits(uint8_t raw) {
for (int i = 7; i >= 0; i--) Serial.print(sensorOn(raw, i) ? "1" : "0");
}

int countActiveSensors(uint8_t raw) {
int c = 0;
for (int i = 0; i < 8; i++) if (sensorOn(raw, i)) c++; return c;
}

float getLinePosition() {
uint8_t raw = bar.getRaw(); if (raw == 0) return 99.0;

float weightedSum = 0.0;
float totalWeight = 0.0;
for (int i = 0; i < 8; i++) {
if (sensorOn(raw, i)) {
float pos = FLIP_SENSOR ? ((float)i - 3.5) : (3.5 - (float)i); weightedSum += pos;
totalWeight += 1.0;
}
}
return weightedSum / totalWeight;
}

// ============================================= // STATE RESET
// ============================================= void resetStateForStart() {
integral = 0.0;
lastError = 0.0;
lastKnownDir = 0;
lastLeftSpeed = 0;
lastRightSpeed = 0;
wasInTurn = false;
junctionDetected = false;
junctionStartTime = 0;
lastJunctionTime = millis(); junctionCount = 0;
launchPhase = LAUNCH_IDLE; junctionPhase = JUNC_IDLE; forwardDirection = true;
currentTarget = TARGET_NONE; votesOpponent = 0;
votesSelf = 0;
votesNone = 0;
escArmed = false;
inHomeBaseBypass = false;
// Invalidate PWM caches so the first write of this run definitely // goes through (in case something was previously written that // happens to match the new value we want to send). lastEscThrottleUs = -1;
lastEscDirAngleDeg = -1;
lastFlapAngleDeg = -1;
}

void killAll() {
// Order matters: stop the mechanism that's most dangerous first. // ESC + drive motors first, then everything else.
setEsc(0.0); | // throttle to zero immediately
stopMotors(); | // drive motors off
setFlap(FLAP_CENTER); | // flap to neutral

forceShooterChannelsOff(); | // explicitly cut shooter PWM signals

running = false;
launchPhase = LAUNCH_IDLE;
junctionPhase = JUNC_IDLE; junctionDetected = false;
inStartupGrace = false;
inHomeBaseBypass = false;
gracePhase = GRACE_INIT;
escArmed = false;

// Clear vote counters so a stale state doesn't carry over votesOpponent = 0;
votesSelf = 0;
votesNone = 0;

// Invalidate PWM caches — the next setEsc/setFlap/setServoAngle // call should always write through, since forceShooterChannelsOff() // bypassed the cache and put hardware in an unknown state. lastEscThrottleUs = -1;
lastEscDirAngleDeg = -1;
lastFlapAngleDeg = -1;

Serial.println(F("[killAll] all systems stopped"));
}

// =============================================
// COMMAND HANDLERS
// =============================================
void handleStart() {
if (running) return;
Serial.println(F("=== START — entering 10s startup grace ===")); resetStateForStart();
running = true;

stopMotors();
setEsc(0.0);
setFlap(FLAP_CENTER);

runStartTime = millis();
inStartupGrace = true;

gracePhase = GRACE_INIT;
gracePhaseStart = millis();
}

void handleStop() {
Serial.println(F("=== STOP ===")); killAll();
}

void handleSerial() {
while (arduino1Link.available()) {
String cmd = arduino1Link.readStringUntil('\n'); cmd.trim();
if (cmd.length() == 0) continue;

if (cmd == "START") {
handleStart();
} else if (cmd == "STOP") {
handleStop();
} else if (cmd == "TEAM:RED") {
bool changed = (currentTeam != TEAM_RED); currentTeam = TEAM_RED;
if (escArmed) {
setMotorDirectionForTeam();
}
if (changed) {
Serial.print(F("Team: RED | DIR angle = "));
Serial.print(MOTOR_DIR_RED);
Serial.println(escArmed ? F(" (applied)") : F(" (deferred until armed)"));
}

} else if (cmd == "TEAM:BLUE") {
bool changed = (currentTeam != TEAM_BLUE); currentTeam = TEAM_BLUE;
if (escArmed) {
setMotorDirectionForTeam();
}
if (changed) {
Serial.print(F("Team: BLUE | DIR angle = "));
Serial.print(MOTOR_DIR_BLUE);
Serial.println(escArmed ? F(" (applied)") : F(" (deferred until armed)"));
}
} else if (cmd == "TARGET:SELF") {
currentTarget = TARGET_SELF;
if (junctionPhase == JUNC_WAIT_FOR_TARGET) { votesSelf++;
}
} else if (cmd == "TARGET:OPPONENT") { currentTarget = TARGET_OPPONENT;
if (junctionPhase == JUNC_WAIT_FOR_TARGET) { votesOpponent++;
}
} else if (cmd == "TARGET:NONE") { currentTarget = TARGET_NONE;
if (junctionPhase == JUNC_WAIT_FOR_TARGET) { votesNone++;
}
}
}
}

// ============================================= // GRACE PERIOD STATE MACHINE
// ============================================= void updateGrace(unsigned long now) {
unsigned long elapsed = now - gracePhaseStart;

switch (gracePhase) {

case GRACE_INIT:
setEscDirectionToArmRef(); setEsc(0.0);
gracePhase = GRACE_ARMING;
gracePhaseStart = now;
Serial.print(F("[GRACE] arming ESC at reference angle ")); Serial.println(ESC_ARM_REF_ANGLE);
break;

case GRACE_ARMING:
setEscDirectionToArmRef(); setEsc(0.0);
if (elapsed >= ESC_ARM_MS) { escArmed = true;
setMotorDirectionForTeam();
gracePhase = GRACE_IDLE;
gracePhaseStart = now;
Serial.print(F("[GRACE] ESC armed — direction set for team ")); Serial.print(currentTeam == TEAM_RED ? F("RED (") : F("BLUE (")); Serial.print(currentTeam == TEAM_RED ? MOTOR_DIR_RED : MOTOR_DIR_BLUE); Serial.println(F(")"));
}
break;

case GRACE_IDLE:
break;
}
}

// ============================================= // JUNCTION HANDLING STATE MACHINE
// ============================================= void enterJunctionWait() { Serial.print(F("Junction #"));

Serial.print(junctionCount);
Serial.println(F(" — driving forward briefly to align over junction...")); // Don't stop yet — drive forward a bit to position the launcher
// properly over the bucket. JUNC_APPROACH will hold this for
// JUNCTION_DRIVE_MS, then transition to vote collection. setMotors(JUNCTION_FORWARD_SPEED, JUNCTION_FORWARD_SPEED);
// Clear vote counters — only votes during the wait phase count. votesOpponent = 0;
votesSelf = 0;
votesNone = 0;
junctionPhase = JUNC_APPROACH; junctionPhaseStart = millis();
}

void updateJunction() {
// Always check for STOP first — junction wait can be up to 5s. handleSerial();
if (!running) {
return; // killAll() already shut everything down
}

unsigned long now = millis();
unsigned long elapsed = now - junctionPhaseStart;

switch (junctionPhase) {

case JUNC_APPROACH:
// Drive forward briefly so the launcher ends up properly aligned // with the bucket (the IR sensor leads the body, so by the time // we detect the junction we're not yet centered on it). setMotors(JUNCTION_FORWARD_SPEED, JUNCTION_FORWARD_SPEED);
if (elapsed >= JUNCTION_DRIVE_MS) {
Serial.println(F(" -> aligned, collecting TARGET votes for 5s...")); stopMotors();
// Reset vote counters again here in case any TARGET messages
// arrived during the approach phase — we only want votes from
// the actual wait window.
votesOpponent = 0;
votesSelf = 0;
votesNone = 0;
junctionPhase = JUNC_WAIT_FOR_TARGET; junctionPhaseStart = now;
}
break;

case JUNC_WAIT_FOR_TARGET:
stopMotors();
// Wait the full TARGET_WAIT_MS to collect votes — this gives time
// to handle:
// | 1. Noisy classifications (e.g. RED@1500Hz briefly mis-read as 750Hz)
// | 2. IR LED/sensor misalignment causing intermittent NONE readings
// Then decide based on majority vote.
if (elapsed >= TARGET_WAIT_MS) {
Serial.print(F(" votes: OPP="));
Serial.print(votesOpponent); Serial.print(F(" SELF=")); Serial.print(votesSelf);
Serial.print(F(" NONE=")); Serial.println(votesNone);

// Fire only if BOTH:
// | (a) OPPONENT votes > SELF votes | (majority among non-NONE)
// | (b) OPPONENT votes >= MIN_OPPONENT_VOTES | (enough confidence)
bool shouldFire = (votesOpponent > votesSelf) &&
(votesOpponent >= MIN_OPPONENT_VOTES);

if (shouldFire) {
Serial.println(F(" -> FIRING (OPPONENT wins majority)")); junctionPhase = JUNC_IDLE;
launchPhase = LAUNCH_SET_DIRECTION;
launchPhaseStart = now;
} else if (junctionCount >= TOTAL_JUNCTIONS) {

// Final junction, not firing — just stop here, no boost. Serial.println(F(" -> SKIPPING + final junction, stopping in place")); stopMotors();
junctionPhase = JUNC_IDLE;
lastJunctionTime = now;
} else {
Serial.println(F(" -> SKIPPING (insufficient OPPONENT votes)")); junctionPhase = JUNC_SKIP_PAUSE;
junctionPhaseStart = now;
}
}
break;

case JUNC_SKIP_PAUSE:
stopMotors();
if (elapsed >= SKIP_PAUSE_MS) { junctionPhase = JUNC_SKIP_BOOST; junctionPhaseStart = now;
}
break;

case JUNC_SKIP_BOOST: {
// Boost in current travel direction to clear the junction
int s = forwardDirection ? SKIP_BOOST_SPEED : -SKIP_BOOST_SPEED; setMotors(s, s);
if (elapsed >= SKIP_BOOST_MS) {
junctionPhase = JUNC_IDLE;
lastJunctionTime = now;
// Check if we just hit JUNCTIONS_PER_DIRECTION — handled in main loop
}
break;
}

default:
break;
}
}

// ============================================= // LAUNCH STATE MACHINE
// =============================================
void updateLaunch() {
// Always check for STOP first — launch sequence is long (~7s total) // and we want STOP to abort it cleanly.
handleSerial();
if (!running) {
return; // killAll() already shut everything down
}

unsigned long now = millis();
unsigned long elapsed = now - launchPhaseStart;

switch (launchPhase) {

case LAUNCH_SET_DIRECTION: setEsc(0.0);
setMotorDirectionForTeam(); launchPhase = LAUNCH_DIR_SETTLE; launchPhaseStart = now;
break;

case LAUNCH_DIR_SETTLE:
if (elapsed >= DIR_SETTLE_MS) { setEsc(TARGET_THROTTLE);
launchPhase = LAUNCH_SPINUP; launchPhaseStart = now;
}
break;

case LAUNCH_SPINUP:
if (elapsed >= SPINUP_WAIT_MS) { setFlap(getFlapOpenAngleForTeam());

launchPhase = LAUNCH_FLAP_OPEN; launchPhaseStart = now;
}
break;

case LAUNCH_FLAP_OPEN:
if (elapsed >= FLAP_HOLD_MS) { setFlap(FLAP_CENTER);
launchPhase = LAUNCH_FLAP_RETURN; launchPhaseStart = now;
}
break;

case LAUNCH_FLAP_RETURN:
if (elapsed >= FLAP_RETURN_MS) { launchPhase = LAUNCH_POST_FLAP; launchPhaseStart = now;
}
break;

case LAUNCH_POST_FLAP:
if (elapsed >= POST_FLAP_MS) { setEsc(0.0);
launchPhase = LAUNCH_ESC_OFF; launchPhaseStart = now;
}
break;

case LAUNCH_ESC_OFF:
if (elapsed >= 200) {
forceShooterChannelsOff(); launchPhase = LAUNCH_POST_LAUNCH; launchPhaseStart = now;
}
break;

case LAUNCH_POST_LAUNCH:
if (elapsed >= POST_LAUNCH_MS) {
// If this was the final junction, don't boost — just stop here // and let the main loop transition to the permanent stop state. if (junctionCount >= TOTAL_JUNCTIONS) {
stopMotors();
launchPhase = LAUNCH_IDLE;
lastJunctionTime = now;
Serial.print(F("Final junction #")); Serial.print(junctionCount);
Serial.println(F(" — launch done, no boost (stopping in place)")); } else {
// Normal junction: boost forward to clear it
int s = forwardDirection ? START_BOOST_SPEED : -START_BOOST_SPEED; setMotors(s, s);
launchPhase = LAUNCH_RESUME_BOOST;
launchPhaseStart = now;
lastJunctionTime = now;
}
}
break;

case LAUNCH_RESUME_BOOST:
if (elapsed >= START_BOOST_MS) {
launchPhase = LAUNCH_IDLE; Serial.print(F("Resumed after junction #")); Serial.println(junctionCount);
}
break;

default:
break;
}
}

// =============================================

// LINE FOLLOWING (handles both forward and reverse) // ============================================= void doLineFollowing() {
unsigned long now = millis();
uint8_t raw = bar.getRaw();
float position = getLinePosition();
int activeSensors = countActiveSensors(raw);

// Are we still inside the post-bypass sensor-ignore window?
// homeBaseBypassStart is set when bypass begins; junction detection
// is gated for SENSOR_IGNORE_MS from that point. PID line following
// still runs — only junction detection is suppressed.
bool sensorIgnoreActive = (now - homeBaseBypassStart < SENSOR_IGNORE_MS);

// Junction detection — gated by SENSOR_IGNORE_MS and JUNCTION_COOLDOWN_MS if (!sensorIgnoreActive &&
activeSensors >= JUNCTION_SENSOR_COUNT &&
(now - lastJunctionTime > JUNCTION_COOLDOWN_MS)) {

junctionCount++;
lastJunctionTime = now;

Serial.print(F("JUNCTION #")); Serial.print(junctionCount); Serial.print(F("/"));
Serial.print(TOTAL_JUNCTIONS); Serial.print(F(" sensors=")); Serial.print(activeSensors); Serial.print(F(" raw="));
printRawBits(raw);
Serial.print(F(" mode=")); Serial.println(forwardDirection ? F("FWD") : F("REV"));

integral = 0.0;
lastError = 0.0;
wasInTurn = false;

// Go into target wait — vote and decide whether to fire.
// After this junction is fully handled (fire or skip), if we've // hit TOTAL_JUNCTIONS we'll stop permanently in the main loop. enterJunctionWait();
return;
}

// ── Plan B: simple straight reverse, no PID ── if (!forwardDirection && !USE_PID_REVERSE) { setMotors(-BASE_SPEED_REV, -BASE_SPEED_REV); return;
}

// ── Pick PID gains and speeds based on direction ── float kp = forwardDirection ? KP : KP_REV;
float ki = forwardDirection ? KI : KI_REV;
float kd = forwardDirection ? KD : KD_REV;
int baseSpd | = forwardDirection ? BASE_SPEED | : BASE_SPEED_REV;
int curveSpd = forwardDirection ? CURVE_SPEED : CURVE_SPEED_REV; int pivotSpd = forwardDirection ? PIVOT_SPEED : PIVOT_SPEED_REV;

// CASE 1: line lost
if (position == 99.0) {
integral = 0.0;
lastError = 0.0;

if (wasInTurn) {
// Replay last turn motion (already in correct direction) setMotors(lastLeftSpeed, lastRightSpeed);
} else if (lastKnownDir < 0) {
int l = -SEARCH_SPEED;
int r = SEARCH_SPEED;
if (!forwardDirection) { l = -l; r = -r; } setMotors(l, r);
lastLeftSpeed = l;

lastRightSpeed = r;
wasInTurn = true;
} else if (lastKnownDir > 0) {
int l = SEARCH_SPEED;
int r = -SEARCH_SPEED;
if (!forwardDirection) { l = -l; r = -r; } setMotors(l, r);
lastLeftSpeed = l;
lastRightSpeed = r;
wasInTurn = true;
} else {
int s = forwardDirection ? MIN_MOTOR_SPEED : -MIN_MOTOR_SPEED; setMotors(s, s);
}
return;
}

// CASE 2: 90 degree turn (sharp)
if (abs(position) >= PIVOT_THRESHOLD) { integral = 0.0;
lastError = 0.0;

int l, r;
if (position < 0) {
lastKnownDir = -1;
l = -pivotSpd;
r = pivotSpd;
} else {
lastKnownDir = 1;
l = pivotSpd;
r = -pivotSpd;
}
// For pivot, both directions need to rotate the same way relative to // the line. Pivots are symmetric (one wheel forward, other backward), // so no sign flip needed for reverse mode — we still want to align // with the line as seen by the front sensor.
setMotors(l, r);
lastLeftSpeed = l;
lastRightSpeed = r;
wasInTurn = true;
return;
}

// CASE 3: normal PID line following
float error = position;
if (abs(error) < CENTER_DEADBAND) error = 0.0;

if (error < -0.15) lastKnownDir = -1;
else if (error > 0.15) lastKnownDir = 1;

// For reverse mode, flip the error sign so PID corrects in the right // sense (rear of car moves toward the line, instead of front). float pidError = forwardDirection ? error : -error;

float P = kp * pidError;
if ((pidError > 0 && lastError < 0) || (pidError < 0 && lastError > 0)) { integral = 0.0;
}
integral += pidError;
integral = constrain(integral, -25.0, 25.0);

float I = ki * integral;
float D = kd * (pidError - lastError); lastError = pidError;

float correction = P + I + D;

int currentBaseSpeed;
if (abs(position) > CURVE_THRESHOLD) { currentBaseSpeed = curveSpd; wasInTurn = true;
} else {

currentBaseSpeed = baseSpd; wasInTurn = false;
}

int leftSpeed = currentBaseSpeed + (int)(correction * (float)currentBaseSpeed); int rightSpeed = currentBaseSpeed - (int)(correction * (float)currentBaseSpeed);

// Reverse mode: negate both motor outputs (drive backwards)
if (!forwardDirection) {
leftSpeed = -leftSpeed;
rightSpeed = -rightSpeed;
}
leftSpeed | = constrain(leftSpeed, | -MAX_SPEED, MAX_SPEED);
rightSpeed = constrain(rightSpeed, -MAX_SPEED, MAX_SPEED);

lastLeftSpeed = leftSpeed;
lastRightSpeed = rightSpeed;

setMotors(leftSpeed, rightSpeed);
}

// ============================================= // SETUP
// ============================================= void setup() {
Serial.begin(9600);
arduino1Link.begin(9600);
arduino1Link.setTimeout(50);

Wire.begin();

pwmDrive.begin();
pwmDrive.setOscillatorFrequency(25000000); pwmDrive.setPWMFreq(1000);

pwmShoot.begin();
pwmShoot.setOscillatorFrequency(25000000); pwmShoot.setPWMFreq(50);

delay(100);

stopMotors();
setEsc(0.0);
setFlap(FLAP_CENTER);

setEscDirectionToArmRef(); escArmed = false;

if (bar.begin() == false) {
Serial.println(F("ERROR: line follower array not found.")); while (1) {
stopMotors();
handleSerial();
delay(200);
}
}

Serial.println(F("=== READY — waiting for START ==="));
}

// =============================================
// MAIN LOOP
// =============================================
void loop() {
// Always check serial first — STOP must be honoured immediately handleSerial();

if (!running) {
return;
}

unsigned long now = millis();

// ── Startup grace period ──
if (inStartupGrace) {
if (now - runStartTime >= STARTUP_GRACE_MS) {
Serial.println(F("=== Grace done — entering home base bypass ===")); inStartupGrace = false;
inHomeBaseBypass = true;
homeBaseBypassStart = now;
// Start driving forward immediately. We'll keep driving and // ignoring the line/junction sensors until HOME_BASE_BYPASS_MS // elapses, so the line at the home base doesn't get counted // as a junction.
setMotors(HOME_BASE_BYPASS_SPEED, HOME_BASE_BYPASS_SPEED);
} else {
stopMotors();
updateGrace(now);
return;
}
}

// ── Home base bypass: drive forward at boost speed, ignore everything ──
if (inHomeBaseBypass) {
if (now - homeBaseBypassStart >= HOME_BASE_BYPASS_MS) {
Serial.println(F("=== Home base bypass motion done — line following begins (junction detection still off) ==="));
inHomeBaseBypass = false;
// Reset PID state for clean line following start.
integral = 0.0;
lastError = 0.0;
wasInTurn = false;
// NOTE: we don't return here — fall through to doLineFollowing()
// so the robot starts following the line immediately. Junction
// detection is gated separately by SENSOR_IGNORE_MS (see
// doLineFollowing) so the home base line isn't counted as a junction. } else {
// Keep driving forward at boost speed — DO NOT read sensors at all setMotors(HOME_BASE_BYPASS_SPEED, HOME_BASE_BYPASS_SPEED);
return;
}
}

// ── Launch sequence in progress? ── if (launchPhase != LAUNCH_IDLE) { updateLaunch();
return;
}

// ── Junction handling (target wait / skip) in progress? ── if (junctionPhase != JUNC_IDLE) {
updateJunction();
return;
}

// ── Done with TOTAL_JUNCTIONS junctions? Stop permanently. ──
// We check this here (after junction/launch phases have returned to IDLE) // so the last junction's launch or skip sequence completes cleanly.
if (junctionCount >= TOTAL_JUNCTIONS) {
Serial.print(F("=== "));
Serial.print(TOTAL_JUNCTIONS);
Serial.println(F(" junctions reached — STOPPING ===")); killAll();
return;
}

// ── Normal line following (forward or reverse) ── doLineFollowing();
}

# Circuit Schematic (KiCAD)

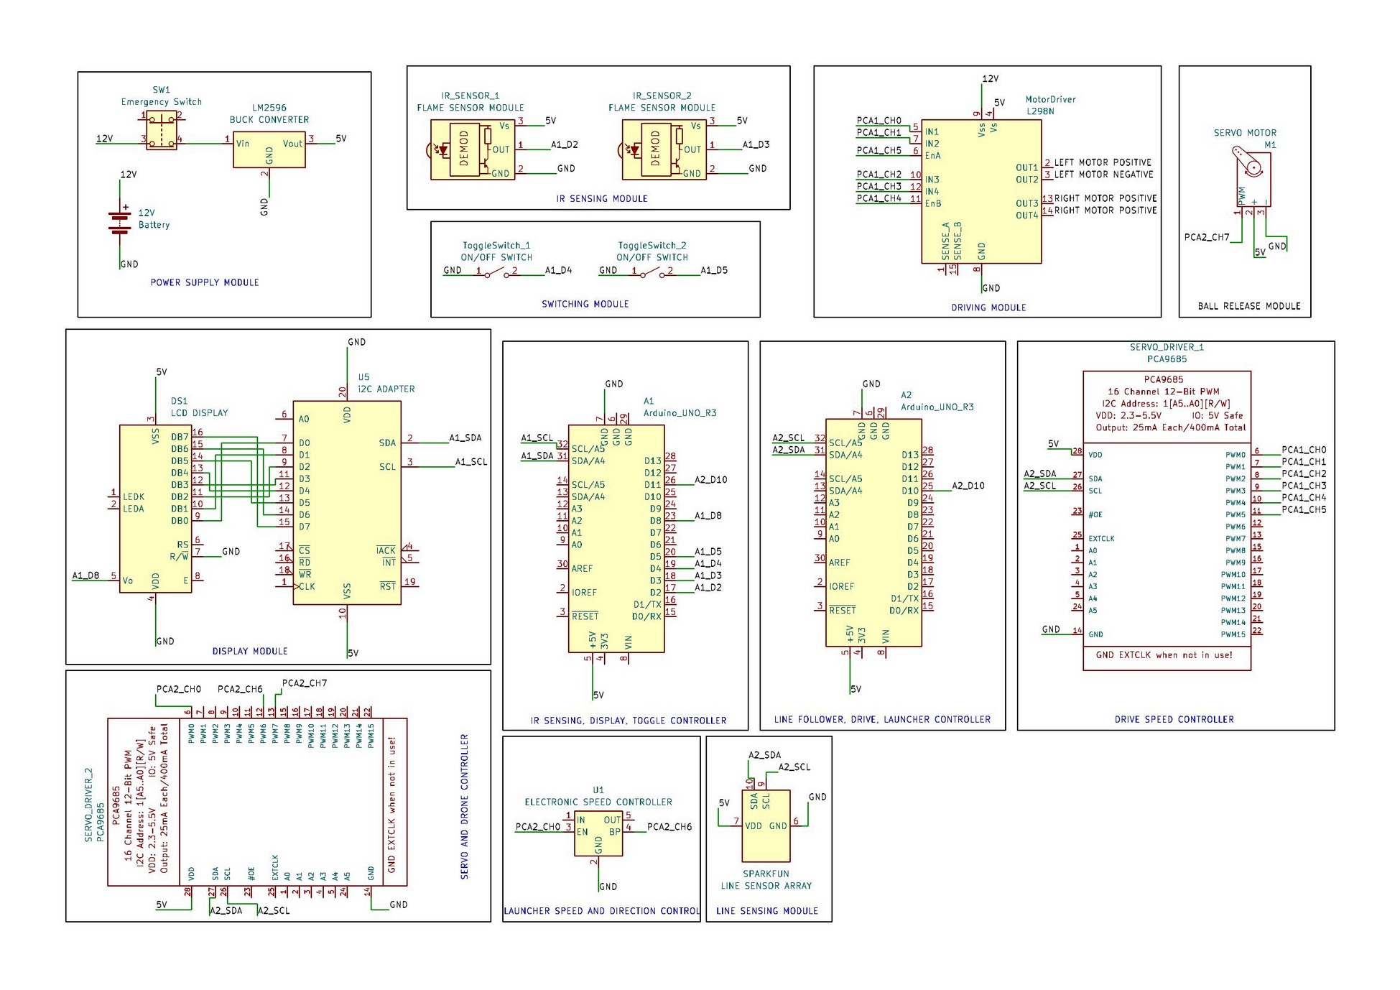
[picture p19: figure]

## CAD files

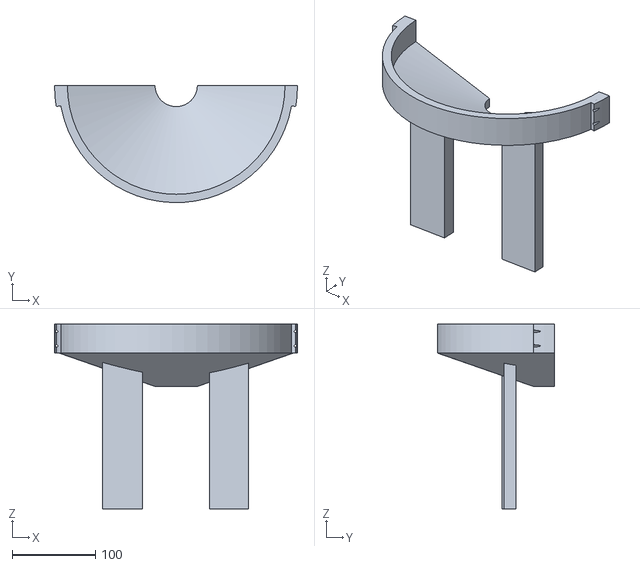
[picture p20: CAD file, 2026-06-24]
hardware/CAD/Hopper_part 2.STL
292.2 x 140.8 x 222.2

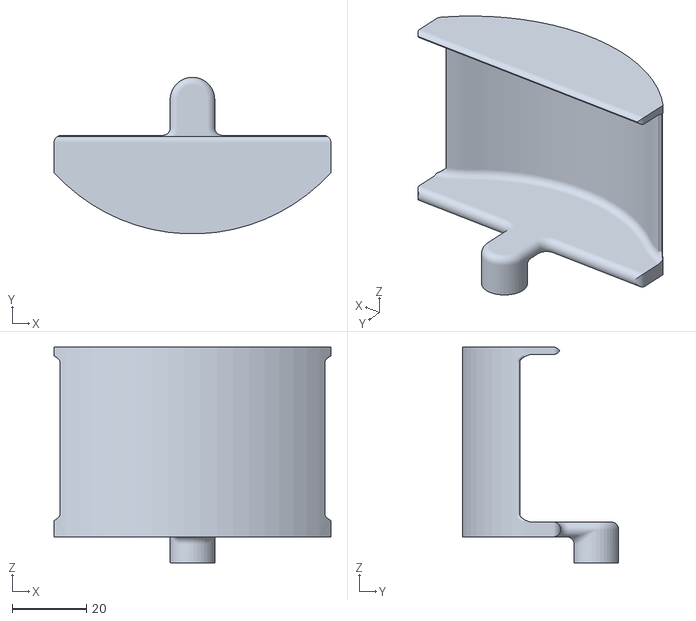
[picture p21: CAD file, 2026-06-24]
hardware/CAD/ball_holder_flap.STL
74.4 x 42.0 x 58.0

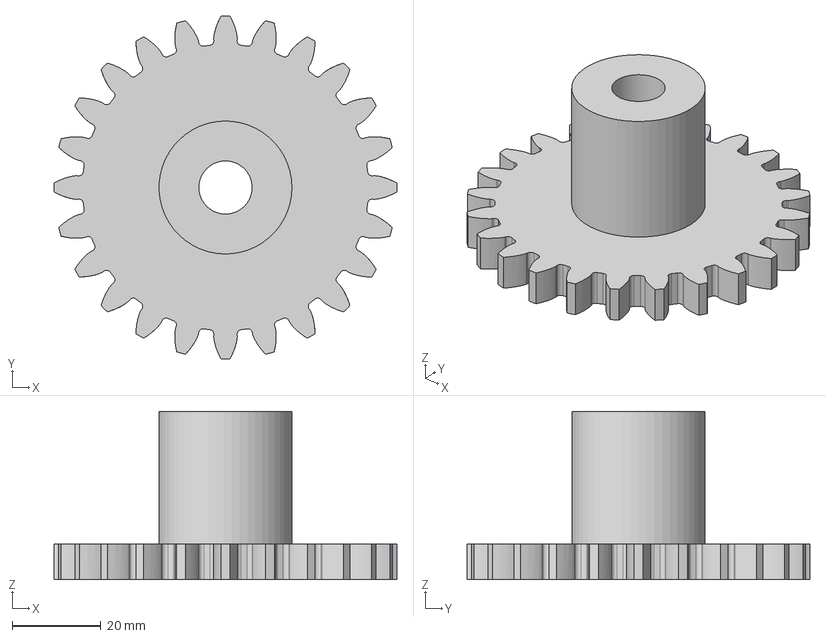
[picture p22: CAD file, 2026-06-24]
hardware/CAD/Spur Gear 24 teeth driven.step
77.4 x 77.4 x 38.0 mm

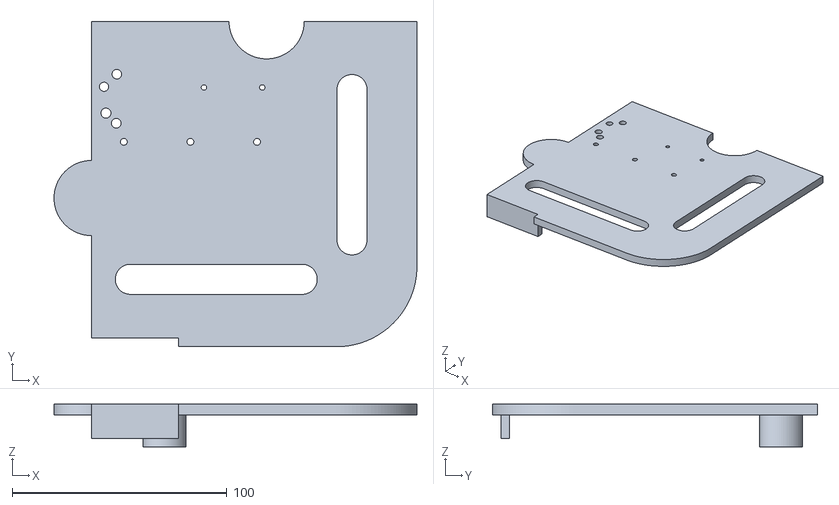
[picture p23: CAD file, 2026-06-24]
hardware/CAD/Body1_wdisplay.stl
169.0 x 151.5 x 20.0

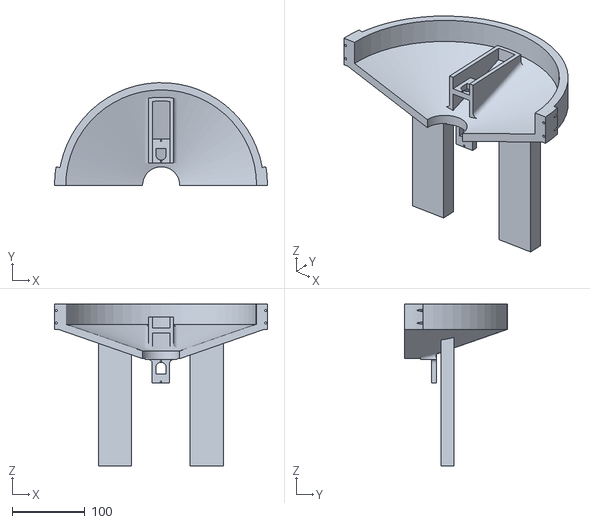
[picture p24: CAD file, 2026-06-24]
hardware/CAD/Hopper_part 1.STL
292.2 x 140.8 x 222.2

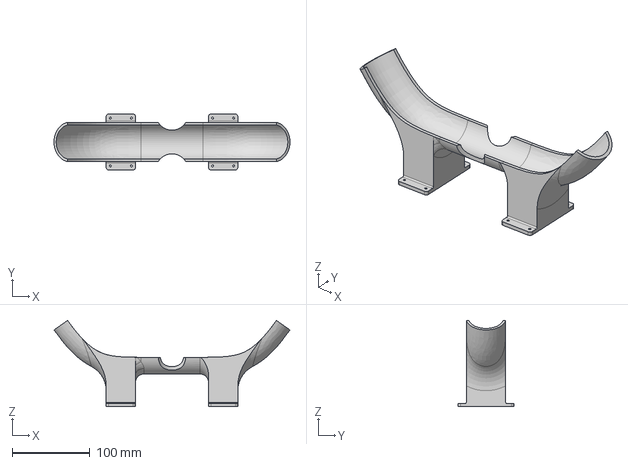
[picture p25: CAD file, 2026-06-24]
hardware/CAD/launcher_ramp.step
303.9 x 72.2 x 111.0 mm

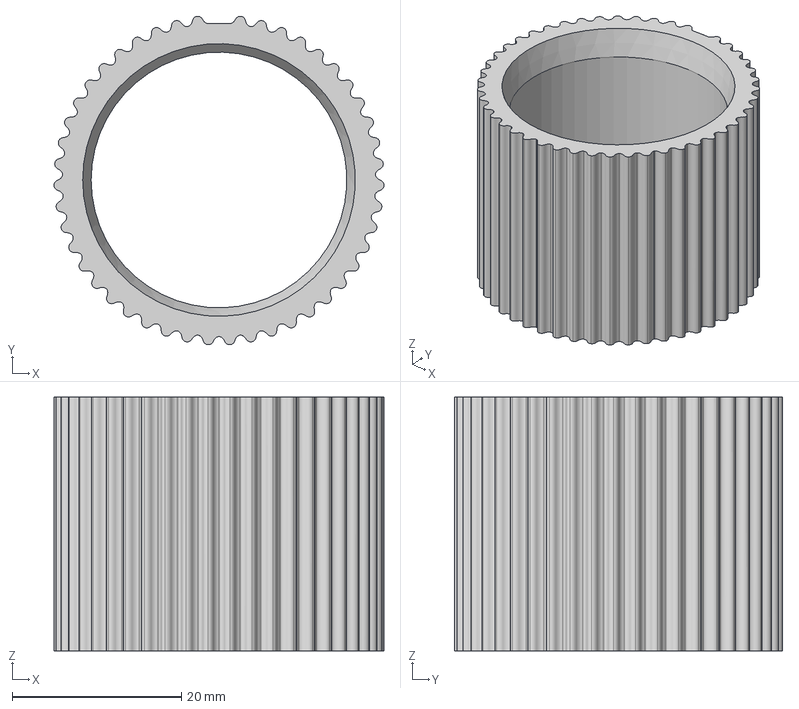
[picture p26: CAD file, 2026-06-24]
hardware/CAD/TPU_sleeve.step
39.0 x 38.8 x 30.0 mm

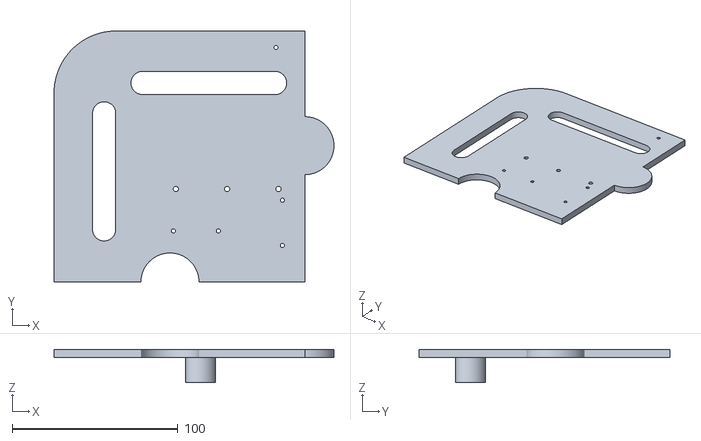
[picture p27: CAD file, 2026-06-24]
hardware/CAD/Body4_forcam.stl
169.0 x 151.5 x 20.0

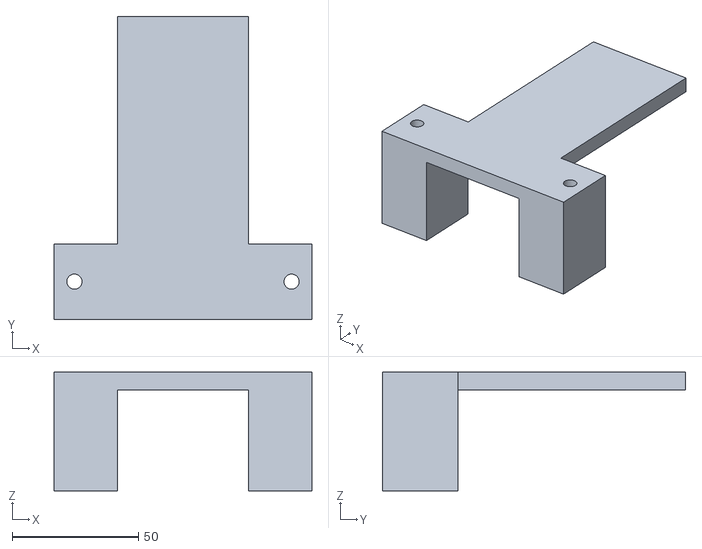
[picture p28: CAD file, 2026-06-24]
hardware/CAD/battery_chassis_attachment.STL
102.0 x 120.0 x 47.0

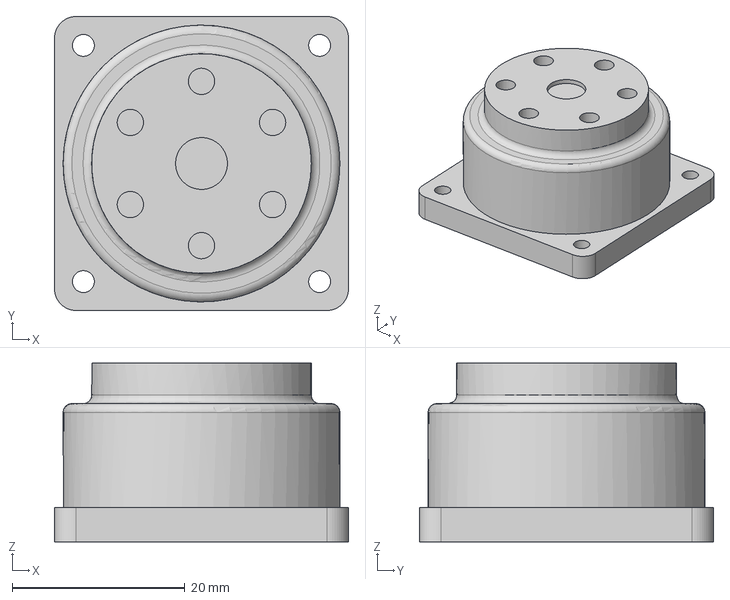
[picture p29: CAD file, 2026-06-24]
hardware/CAD/Driven_base.step
34.0 x 34.0 x 20.7 mm

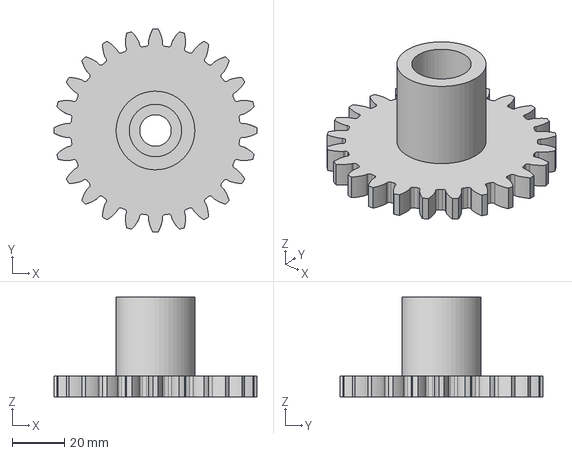
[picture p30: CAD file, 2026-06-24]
hardware/CAD/Spur Gear 24 teeth_drive.step
77.4 x 77.4 x 38.0 mm

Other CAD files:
hardware/CAD/Body2_wdisplay.stl
hardware/CAD/Body3_forcam.stl

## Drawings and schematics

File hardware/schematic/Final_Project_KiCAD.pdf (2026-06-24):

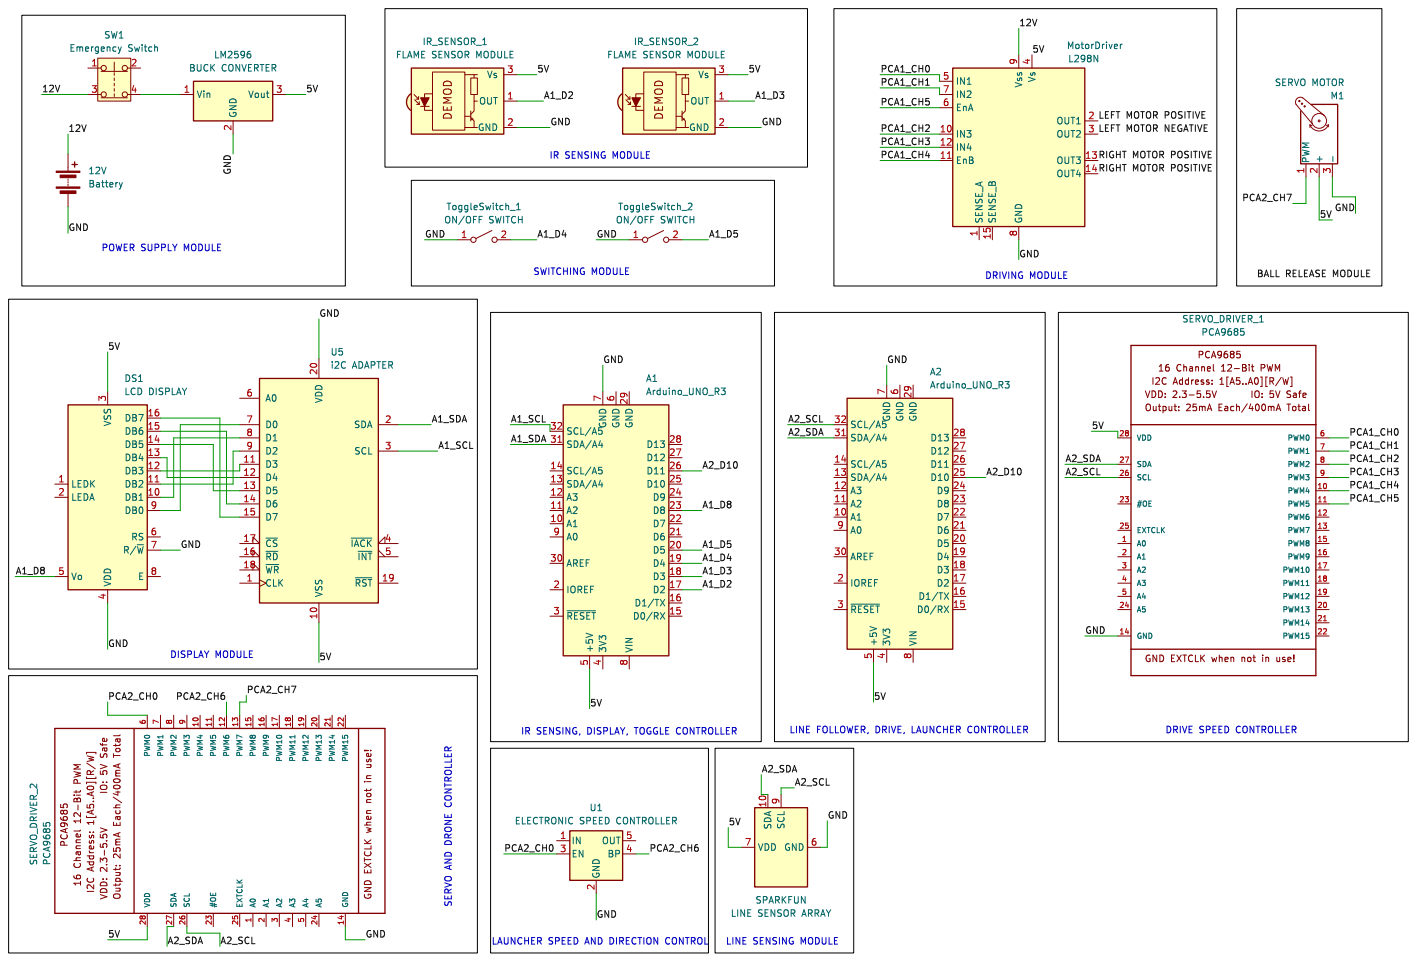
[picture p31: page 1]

RIGHT MOTOR POSITIVE

LAUNCHER SPEED AND DIRECTION CONTROL DISPLAY MODULE

IR SENSING, DISPLAY, TOGGLE CONTROLLER

2 OUT 5 BP 4 U1 ELECTRONIC SPEED CONTROLLER
